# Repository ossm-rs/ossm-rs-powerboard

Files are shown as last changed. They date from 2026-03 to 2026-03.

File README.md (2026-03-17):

# OSSM-RS Powerboard

Power management PCB for AIM family motors, designed to pair with the Industrial ESP32-S3-RS485-CAN control board by Waveshare and run with OSSM-RS software.

This board is inspired by and builds on the OSSM hardware concept from KinkyMakers:
- OSSM-RS software: https://github.com/ossm-rs/ossm
- Original OSSM hardware/research: https://github.com/KinkyMakers/OSSM-hardware/tree/main

## What This Board Does

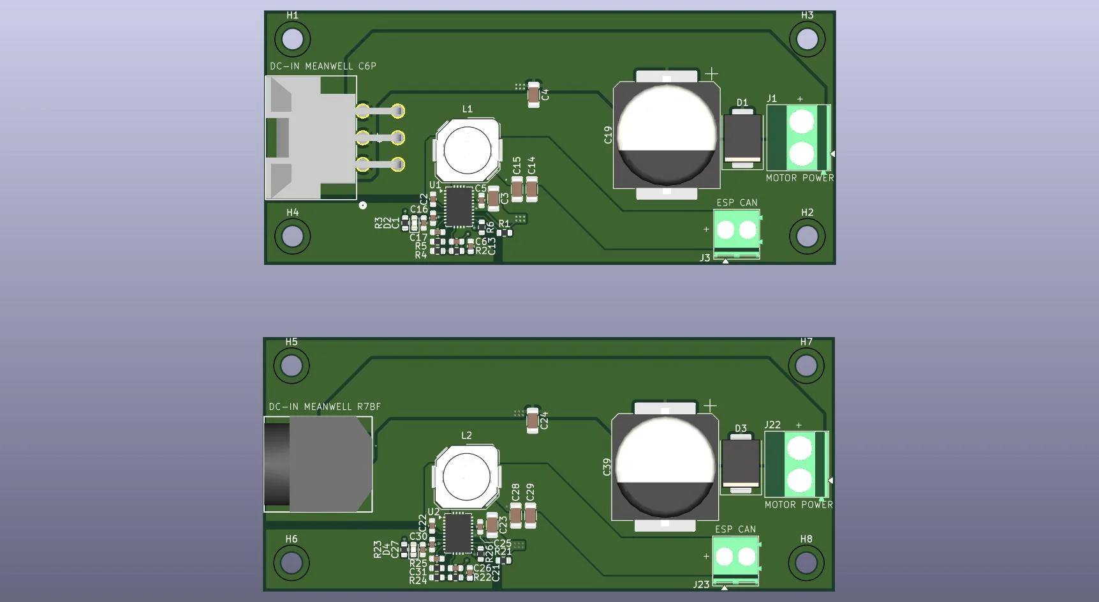
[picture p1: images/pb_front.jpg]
Powerboard diagram


- Accepts DC input from an external power supply.
- Provides 24-36v output for the servo motor.
- Protects from back EMF.
- Provides regulated 12V output for the controller board.
- Supports two input connector variants in this repository:
	- C6P input variant (Molex-style connector).
	- R7BF input variant (barrel jack style, Kycon KPJX-4S).

## System

- Motor family:
	- 60aim40F
	- 57aim30
- Controller:
	- Waveshare Industrial ESP32-S3-RS485-CAN
- PSU
    - Meanwell GST220A36-R7BF
    - Meanwell GST360A36-C6P

Other motor configurations that use 24-36V may also work, but they have not been validated on this board yet.

## Board Variants

- C6P variant:
	- Input connector: C6P 6 Pin Molex footprint
	- Fabrication files prefix: `C6P_*`
	- STEP model: `STEP/powerboard-C6P.step`
- R7BF variant:
	- Input connector: R7BF KPJX-4S footprint
	- Fabrication files prefix: `R7BF_*`
	- STEP model: `STEP/powerboard-R7BF.step`

Do not populate both input connector styles on the same board.

## Usage

- External PSU (C6P or R7BF style) feeds the selected DC-IN connector on this board.
- Motor power is provided at the Motor Power output terminal.
- 12V and GND for the Waveshare board are provided at the ESP/CAN power terminal.
- Motor control and comms (CAN/RS485) are handled by the Waveshare board and motor harness.
- Configure and run OSSM-RS from https://github.com/ossm-rs/ossm.

Use the wiring diagram image below and verify polarity before first power-up.

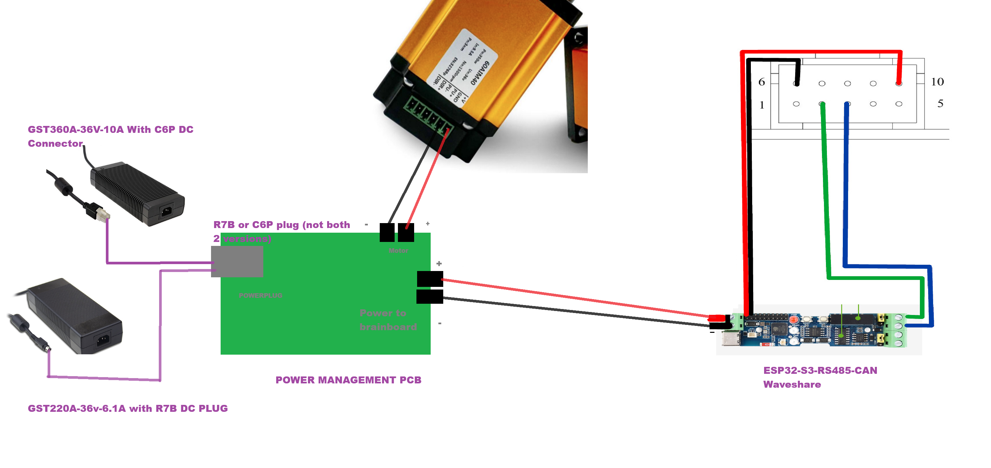
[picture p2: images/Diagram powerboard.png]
Powerboard wiring diagram


## Manufacturing

For assembly orders, use files in `jlcpcb-fabrication-files/`:
- `*_bom.csv` for component list
- `*_positions.csv` for pick-and-place positions

This project is intended for small community group buys through JLCPCB (or another PCB manufacturer). As of 2026-03-17, a typical minimum order on JLCPCB is 5 boards and costs about EUR 100 total.

Estimated cost per board:
- PCB-only share: about EUR 20 per board (EUR 100 / 5)
- With shipping split across 5 boards: about (EUR 100 + shipping) / 5 per board

## Safety Notes

- This is a high-current motor power board; incorrect wiring can damage electronics.
- Always verify connector pinout/polarity against schematic and wiring diagrams.
- Keep wiring secure and strain-relieved.

## Credits

- OSSM-RS maintainers and contributors
- KinkyMakers OSSM hardware project and community research

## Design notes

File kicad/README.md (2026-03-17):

# KiCad Project

Primary design source for the OSSM-RS powerboard.

## Main Files

- `pb-v1.kicad_sch`: Schematic
- `pb-v1.kicad_pcb`: PCB layout
- `pb-v1.kicad_pro`: KiCad project file
- `pb-v1.csv`: Consolidated BOM/export snapshot

## Project Libraries

- `project_symbols/`: Custom symbol libraries
- `project_footprints/`: Custom footprints
- `project_3dshapes/`: 3D models used by footprints

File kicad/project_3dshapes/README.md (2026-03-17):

# project_3dshapes

3D CAD models referenced by custom footprints in this project.

## Contents

This folder includes STEP/IGS/WRL models for:
- Input connectors
- Inductor package
- Regulator or other mechanical-critical parts

## Notes

- Keep model filenames stable once footprints reference them.
- If replacing a model, verify orientation and origin in PCB 3D viewer.
- Prefer STEP for mechanical exchange and keep WRL only when needed by KiCad view pipeline.

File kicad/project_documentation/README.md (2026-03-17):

# project_documentation

Project-local documentation files related to the KiCad design.

## Typical Content

- Design decision notes
- Constraint summaries
- Revision/change logs for PCB updates
- Internal assembly notes for the board

This folder is currently a placeholder and can be expanded as project notes are formalized.

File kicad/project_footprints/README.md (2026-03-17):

# project_footprints

Custom KiCad footprints used by this powerboard project.

## Current Footprints

- `CONN_SDA-42404_06_MOL.kicad_mod`
- `KPJX4S.kicad_mod`
- `KPJX4SS.kicad_mod`
- `L_Wurth_WE-PD-1050P.kicad_mod`

## Maintenance Notes

- Keep courtyard, fab, and 3D model alignment consistent.
- Validate pad numbering against datasheets before release.
- Re-run DRC after footprint updates.

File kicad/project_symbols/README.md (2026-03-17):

# project_symbols

Custom KiCad symbols used in the OSSM-RS powerboard schematic.

## Current Files

- `2026-01-18_19-45-22.kicad_sym`
- `Inductor_Wurth_WE-PD.kicad_sym`
- `KPJX-4S-S.kicad_sym`
- `KPJX-4S.kicad_sym`

## Maintenance Notes

- Keep symbol pin names/numbers synchronized with corresponding footprints.
- Add datasheet links and key fields (MPN, voltage/current where relevant).
- Run ERC after symbol changes.

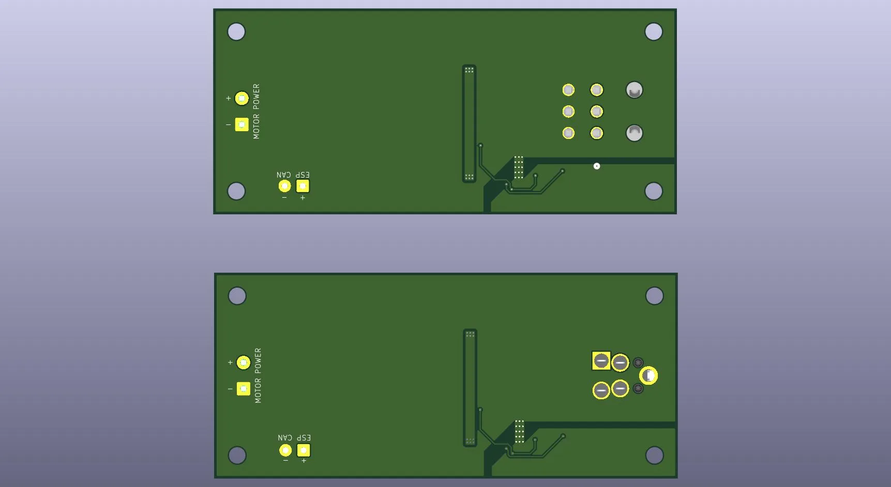
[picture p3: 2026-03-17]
images/pb_back.jpg

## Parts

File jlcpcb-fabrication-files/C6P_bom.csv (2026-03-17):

Designator | Footprint | Quantity | Value | LCSC Part #
C1 | 0603 | 1 | 1uF | C15849
C13, C5 | 0603 | 2 | 100nF | C14663
C14, C15, C3, C4 | 1206 | 4 | 10uF | C89632
C16 | 0603 | 1 | 2.2uF | C23630
C19 | CP_Elec_16x17.5 | 1 | 1mF | C2164559
C2 | 0603 | 1 | 470nF | C1623
C6 | 0603 | 1 | 5.1pF | C61816
D1 | D_SMC | 1 | SMCJ40CA | C80273
D2 | 0603 | 1 | GREEN | C12065
J1 | TerminalBlock_Phoenix_MKDS-1,5-2-5.08_1x02_P5.08mm_Horizontal | 1 | Motor Power | C8465
J3 | TerminalBlock_Phoenix_PT-1,5-2-3.5-H_1x02_P3.50mm_Horizontal | 1 | 12V ESP CAN | C466970
J4 | CONN_SDA-42404_06_MOL | 1 | Molex 15246060 | C563687
L1 | L_Wurth_WE-PD-1050P | 1 | 22uH | C2651173
R1, R2 | 0603 | 2 | 100k | C25803
R3 | 0603 | 1 | 10k | C25804
R4 | 0603 | 1 | 9.1k | C23260
R6 | 0603 | 1 | 100 | C22775
U1 | Texas_RNP0030B_WQFN-30-1EP_4x6mm_P0.5mm_EP1.8x4.5mm_ThermalVias | 1 | LM76003 | C470958

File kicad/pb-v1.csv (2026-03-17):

Reference | Qty | Value | DNP | Exclude from BOM | Exclude from Board | Footprint | Datasheet | MPN | Voltage
C1,C21 | 2 | 1uF |  |  |  | Capacitor_SMD:C_0603_1608Metric | ~ | C15849 | 50V
C2,C22 | 2 | 470nF |  |  |  | Capacitor_SMD:C_0603_1608Metric | ~ | C1623 | 25V
C3,C4,C14,C15,C23,C24,C28,C29 | 8 | 10uF |  |  |  | Capacitor_SMD:C_1206_3216Metric | ~ | C89632 | 25V,50V
C5,C13,C25,C27 | 4 | 100nF |  |  |  | Capacitor_SMD:C_0603_1608Metric | ~ | C14663 | 25V,50V
C6,C26 | 2 | 5.1pF |  |  |  | Capacitor_SMD:C_0603_1608Metric | ~ | C61816
C16,C30 | 2 | 2.2uF |  |  |  | Capacitor_SMD:C_0603_1608Metric | ~C100082 | C23630 | 16V
C17,C31 | 2 | 10nF | DNP |  |  | Capacitor_SMD:C_0603_1608Metric | ~ | C57112 | 50V
C19,C39 | 2 | 1mF |  |  |  | Capacitor_SMD:CP_Elec_16x17.5 | ~865060663015 | C2164559 | 50V
D1,D3 | 2 | D_TVS |  |  |  | Diode_SMD:D_SMC | ~ | C80273
D2,D4 | 2 | GREEN |  |  |  | LED_SMD:LED_0603_1608Metric | ~ | C12065
H1,H2,H3,H4,H5,H6,H7,H8 | 8 | MountingHole |  | Excluded from BOM |  | MountingHole:MountingHole_3.2mm_M3_DIN965 | ~ | -
J1,J22 | 2 | Motor Power |  |  |  | TerminalBlock_Phoenix:TerminalBlock_Phoenix_MKDS-1,5-2-5.08_1x02_P5.08mm_Horizontal | ~ | C8465
J3,J23 | 2 | 12V ESP CAN |  |  |  | TerminalBlock_Phoenix:TerminalBlock_Phoenix_PT-1,5-2-3.5-H_1x02_P3.50mm_Horizontal | ~ | C466970
J4 | 1 | Conn_01x06 |  |  |  | project_footprints:CONN_SDA-42404_06_MOL | ~ | C563687
J21 | 1 | KPJX-4S |  |  |  | project_footprints:KPJX4S | https://www.kycon.com/Pub_Eng_Draw/KPJX-4S.pdf | C7212564
L1,L2 | 2 | 22uH |  |  |  | project_footprints:L_Wurth_WE-PD-1050P | ~7447714220 | C2651173
R1,R2,R21,R22 | 4 | 100k |  |  |  | Resistor_SMD:R_0603_1608Metric | ~ | C25803
R3,R23 | 2 | 10k |  |  |  | Resistor_SMD:R_0603_1608Metric | ~ | C25804
R4,R24 | 2 | 9.1k |  |  |  | Resistor_SMD:R_0603_1608Metric | ~ | C23260
R5,R25 | 2 | 82k | DNP |  |  | Resistor_SMD:R_0603_1608Metric | ~ | C23254
R6,R26 | 2 | 100 |  |  |  | Resistor_SMD:R_0603_1608Metric | ~ | C22775
U1,U2 | 2 | LM76003 |  |  |  | Package_DFN_QFN:Texas_RNP0030B_WQFN-30-1EP_4x6mm_P0.5mm_EP1.8x4.5mm_ThermalVias | https://www.ti.com/lit/ds/symlink/lm76003.pdf | C470958

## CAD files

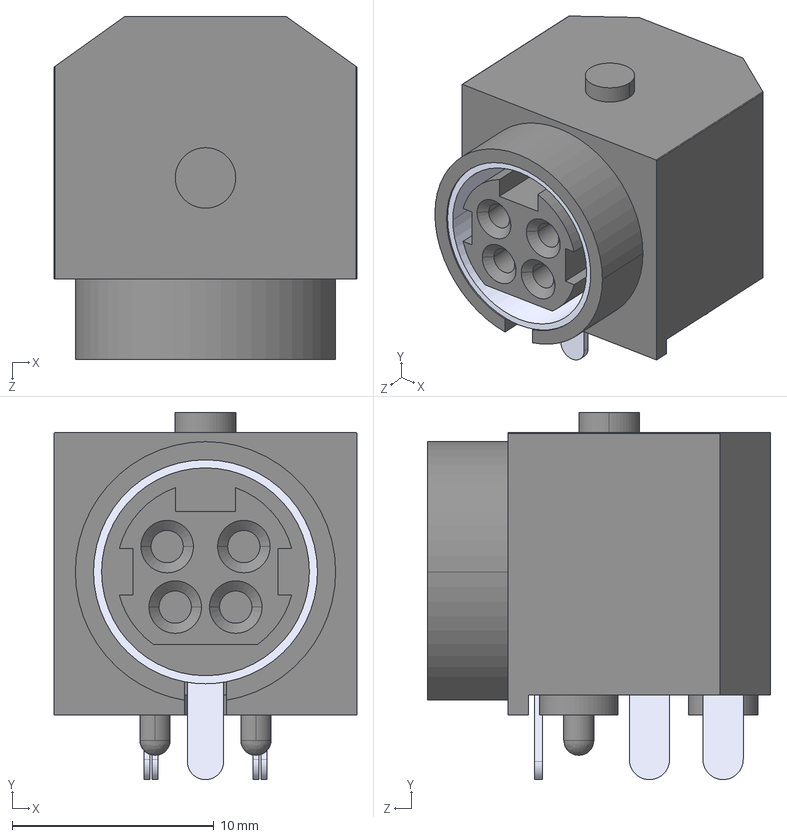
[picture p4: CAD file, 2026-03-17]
kicad/project_3dshapes/KPJX-4S.stp
15.0 x 18.2 x 17.0 mm

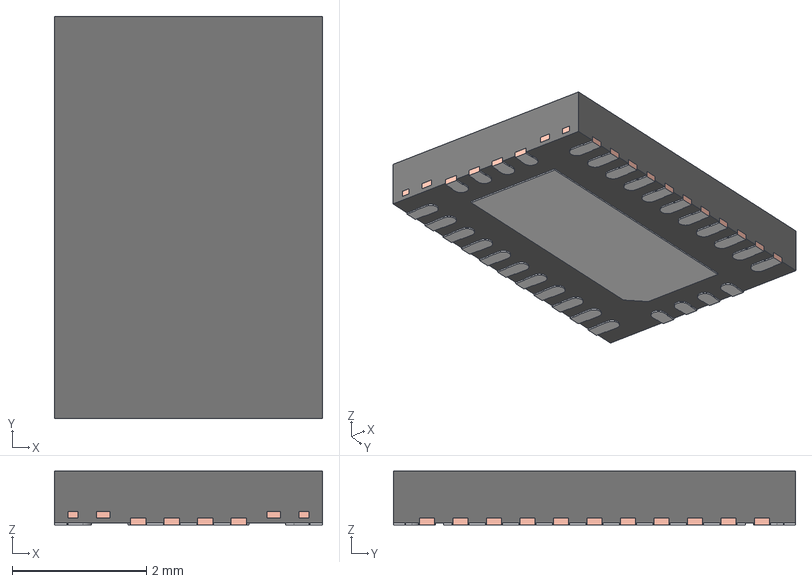
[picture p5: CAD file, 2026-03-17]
kicad/project_3dshapes/RNP0030G.stp
4.00 x 6.00 x 0.8 mm
BODY-QFN
FRAME
PIN1-ID

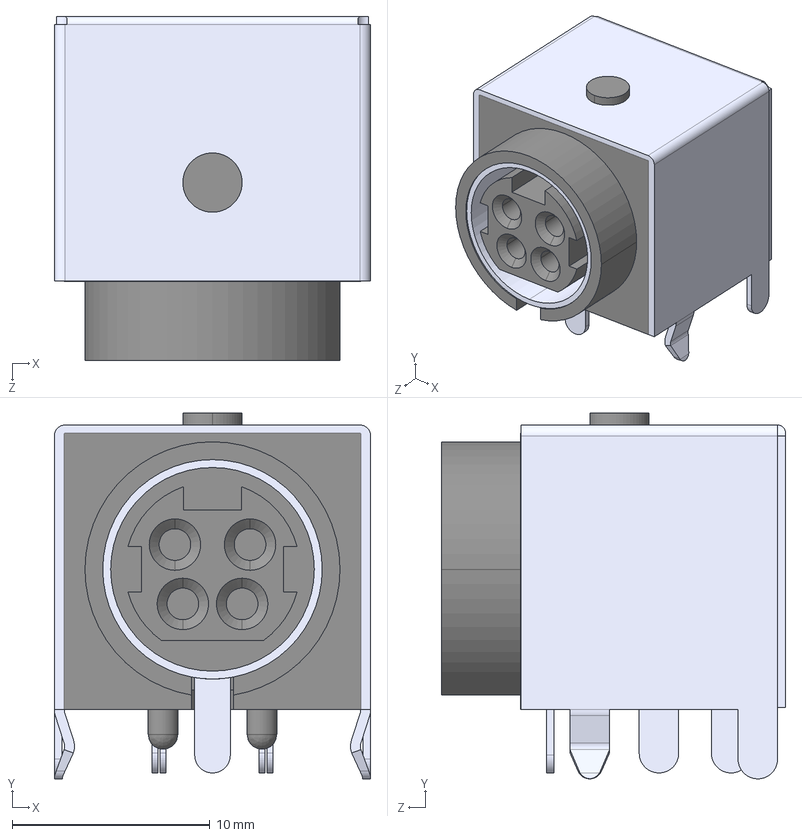
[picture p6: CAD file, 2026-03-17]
kicad/project_3dshapes/KPJX-4S-S.stp
16.0 x 18.5 x 17.4 mm

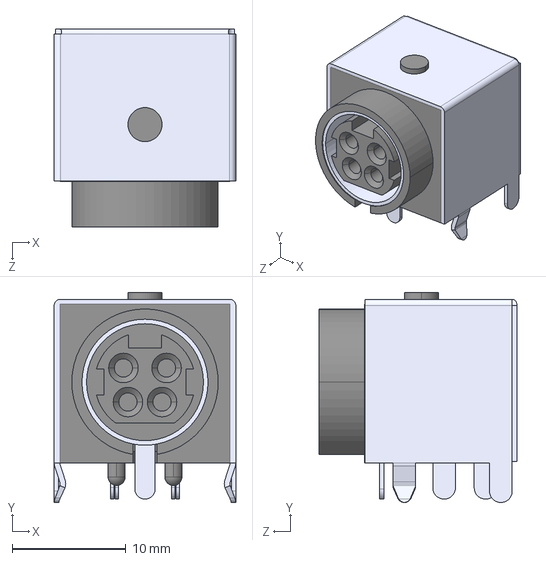
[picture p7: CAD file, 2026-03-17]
kicad/project_3dshapes/KPJX-4S-S_A.STEP
16.0 x 18.5 x 17.4 mm

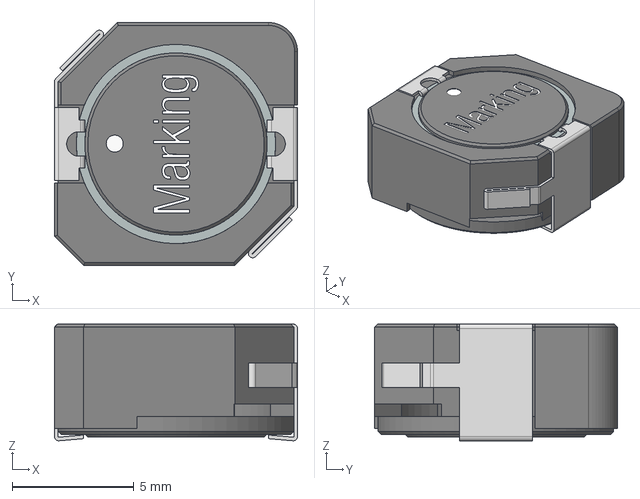
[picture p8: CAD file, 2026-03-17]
kicad/project_3dshapes/L_Wurth_WE-PD-1050P.step
10.0 x 10.0 x 4.80 mm

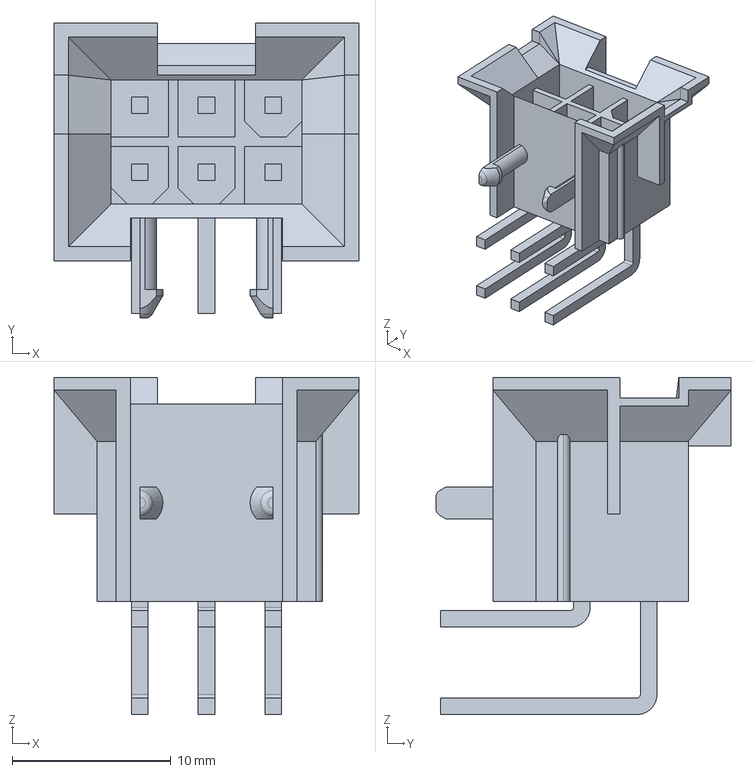
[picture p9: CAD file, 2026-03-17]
kicad/project_3dshapes/0015246060.stp
19.2 x 18.6 x 21.2 mm

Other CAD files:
kicad/project_3dshapes/KPJX-4S_A.STEP
kicad/project_3dshapes/0015246060.igs

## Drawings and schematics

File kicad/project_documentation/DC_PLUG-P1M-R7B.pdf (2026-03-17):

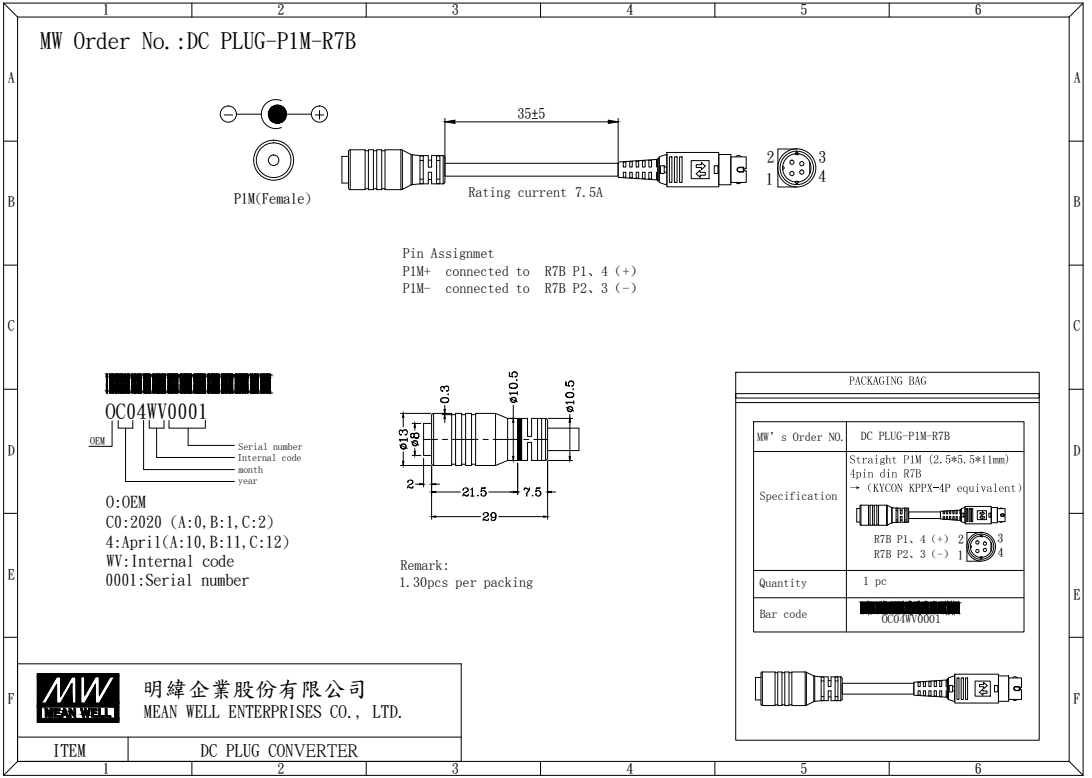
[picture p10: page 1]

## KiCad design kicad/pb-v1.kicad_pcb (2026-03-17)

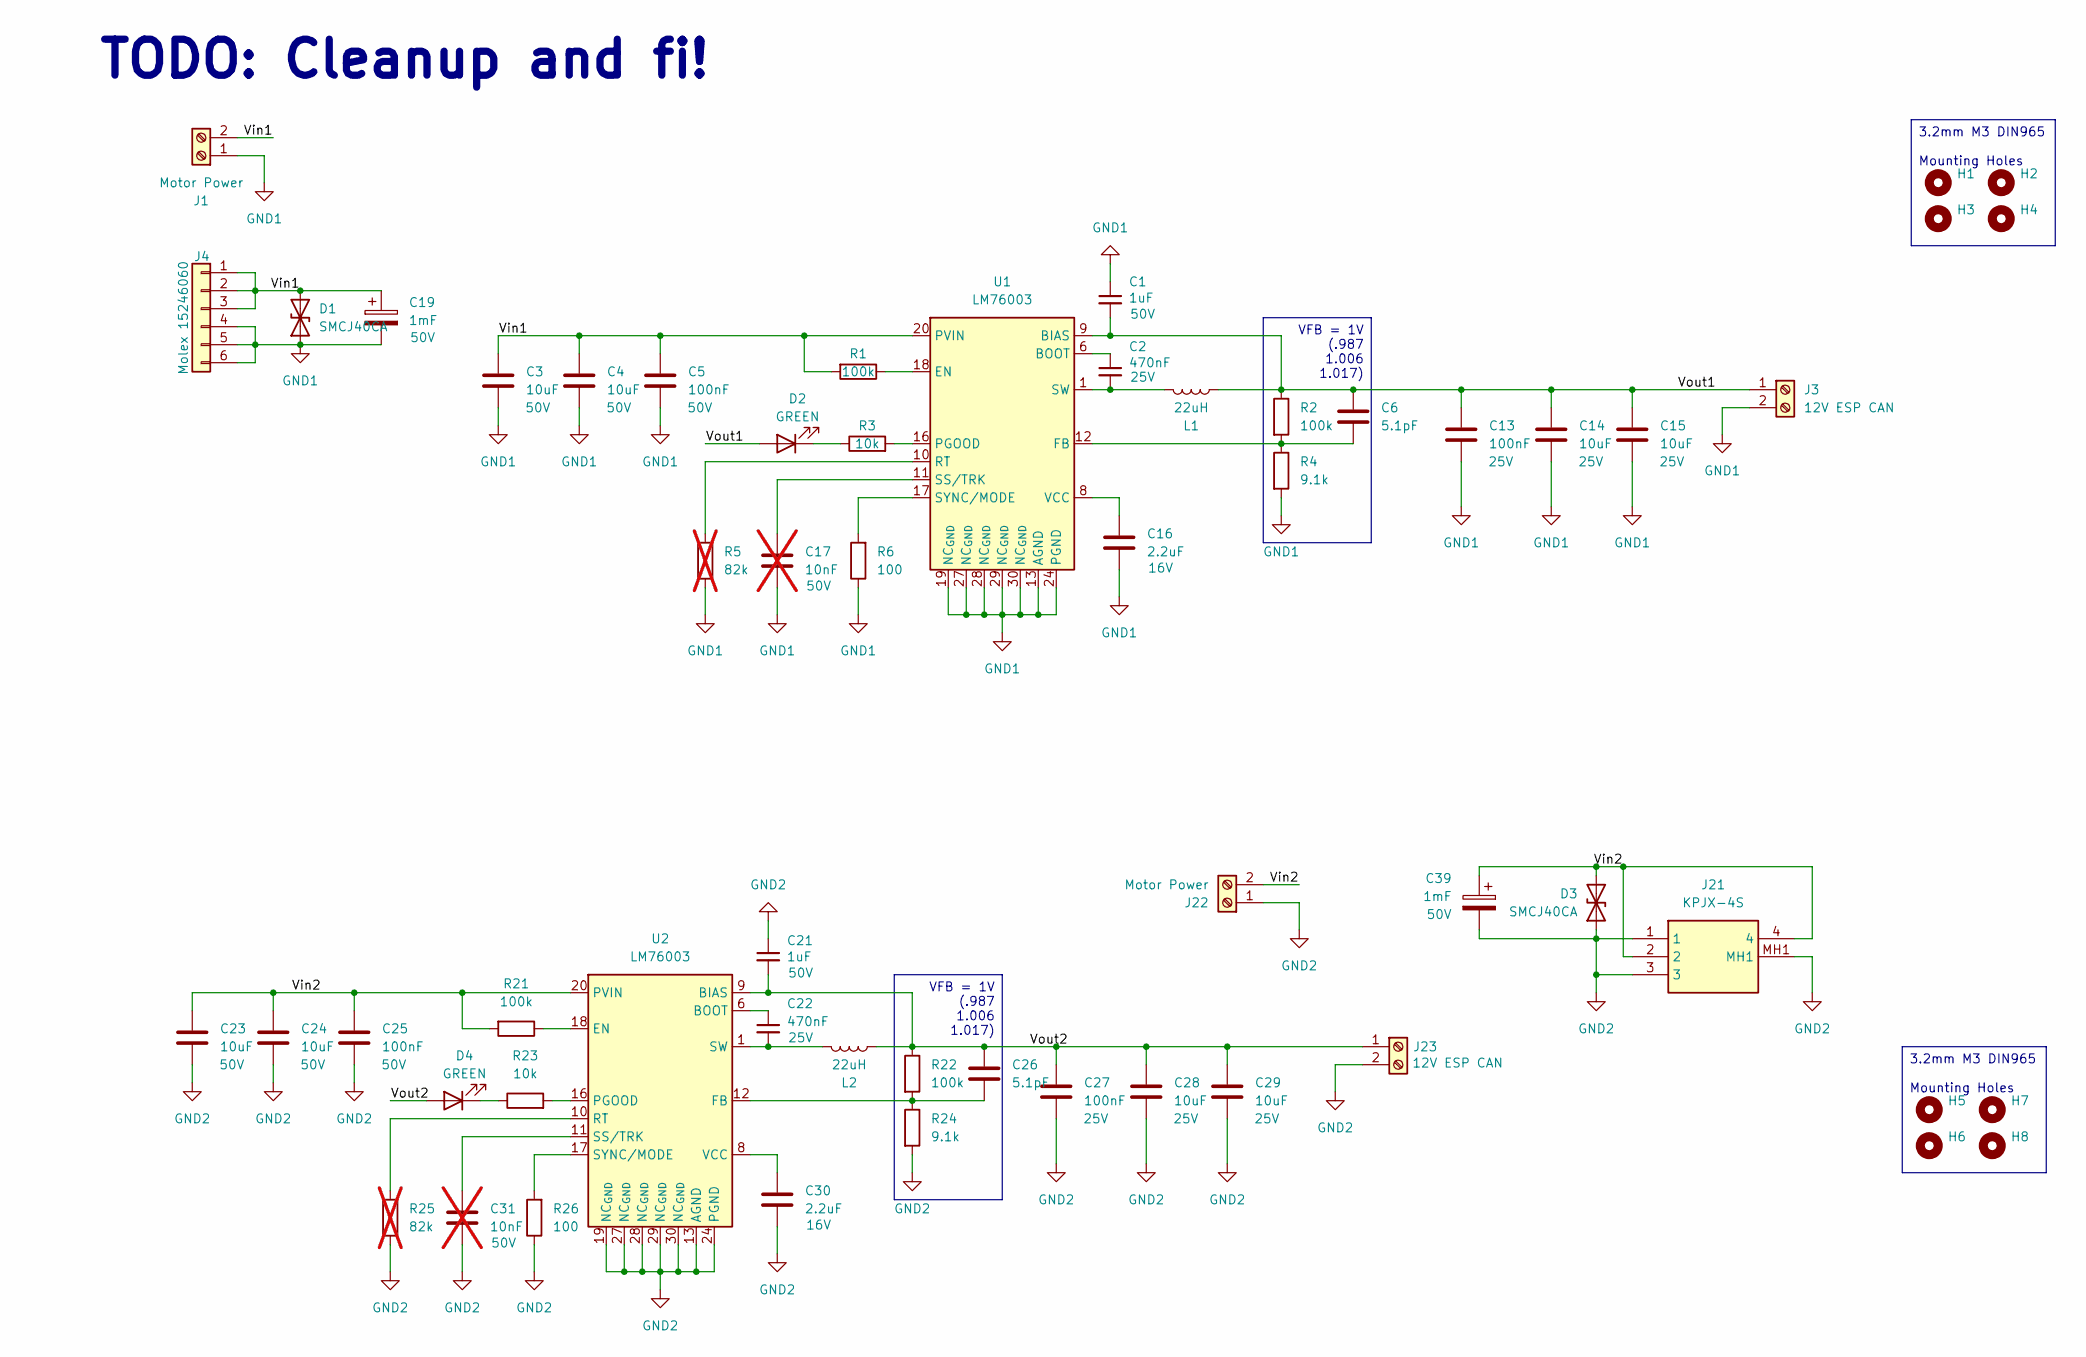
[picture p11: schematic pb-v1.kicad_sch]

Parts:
C1, C21: 1uF; C_0603_1608Metric; Voltage 50V; MPN C15849
C2, C22: 470nF; C_0603_1608Metric; Voltage 25V; MPN C1623
C3, C4, C23, C24: 10uF; C_1206_3216Metric; Voltage 50V; MPN C89632
C5, C25: 100nF; C_0603_1608Metric; Voltage 50V; MPN C14663
C6, C26: 5.1pF; C_0603_1608Metric; MPN C61816
C13, C27: 100nF; C_0603_1608Metric; Voltage 25V; MPN C14663
C14, C15, C28, C29: 10uF; C_1206_3216Metric; Voltage 25V; MPN C89632
C16, C30: 2.2uF; C_0603_1608Metric; Voltage 16V; MPN C23630
C17, C31: 10nF; C_0603_1608Metric; Voltage 50V; MPN C57112; not fitted
C19, C39: 1mF; CP_Elec_16x17.5; Voltage 50V; MPN C2164559
D1, D3: SMCJ40CA; D_SMC; MPN C80273
D2, D4: GREEN; LED_0603_1608Metric; MPN C12065
H1, H2, H3, H4, H5, H6, H7, H8: MountingHole; MountingHole_3.2mm_M3_DIN965
J1, J22: Motor Power; TerminalBlock_Phoenix_MKDS-1,5-2-5.08_1x02_P5.08mm_Horizont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; MPN C8465
J3, J23: 12V ESP CAN; TerminalBlock_Phoenix_PT-1,5-2-3.5-H_1x02_P3.50mm_Horizontal; MPN C466970
J4: Molex 15246060; CONN_SDA-42404_06_MOL; MPN C563687
J21: KPJX-4S; KPJX4S; Manufacturer_Part_Number KPJX-4S; Mouser Part Number 806-KPJX-4S
L1, L2: 22uH; L_Wurth_WE-PD-1050P; MPN C2651173
R1, R2, R21, R22: 100k; R_0603_1608Metric; MPN C25803
R3, R23: 10k; R_0603_1608Metric; MPN C25804
R4, R24: 9.1k; R_0603_1608Metric; MPN C23260
R5, R25: 82k; R_0603_1608Metric; MPN C23254; not fitted
R6, R26: 100; R_0603_1608Metric; MPN C22775
U1, U2: LM76003; Texas_RNP0030B_WQFN-30-1EP_4x6mm_P0.5mm_EP1.8x4.5mm_Thermal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; MPN C470958

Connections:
/Vin1: C3.1, C4.1, C5.1, C19.1, D1.2 (A2), J1.2, J4.1, J4.2, J4.3, R1.2, U1.20 (PVIN), U1.21 (PVIN), U1.22 (PVIN)
/Vin2: C23.1, C24.1, C25.1, C39.1, D3.2 (A2), J21.2, J21.4, J22.2, R21.2, U2.20 (PVIN), U2.21 (PVIN), U2.22 (PVIN)
/Vout1: C1.2, C6.1, C13.1, C14.1, C15.1, D2.2 (A), J3.1, L1.2, R2.1, U1.9 (BIAS)
/Vout2: C21.2, C26.1, C27.1, C28.1, C29.1, D4.2 (A), J23.1, L2.2, R22.1, U2.9 (BIAS)
GND1: C1.1, C3.2, C4.2, C5.2, C13.2, C14.2, C15.2, C16.2, C17.2, C19.2, D1.1 (A1), J1.1, J3.2, J4.4, J4.5, J4.6, R4.2, R5.1, R6.1, U1.13 (AGND), U1.14 (AGND), U1.15 (AGND), U1.19 (NC_{GND}), U1.24 (PGND), U1.25 (PGND), U1.26 (PGND), U1.27 (NC_{GND}), U1.28 (NC_{GND}), U1.29 (NC_{GND}), U1.30 (NC_{GND}), U1.31 (AGND)
GND2: C21.1, C23.2, C24.2, C25.2, C27.2, C28.2, C29.2, C30.2, C31.2, C39.2, D3.1 (A1), J21.1, J21.3, J21.MH1, J22.1, J23.2, R24.2, R25.1, R26.1, U2.13 (AGND), U2.14 (AGND), U2.15 (AGND), U2.19 (NC_{GND}), U2.24 (PGND), U2.25 (PGND), U2.26 (PGND), U2.27 (NC_{GND}), U2.28 (NC_{GND}), U2.29 (NC_{GND}), U2.30 (NC_{GND}), U2.31 (AGND)
unnamed: C2.2, L1.1, U1.1 (SW), U1.2 (SW), U1.3 (SW), U1.4 (SW), U1.5 (SW)
unnamed: C22.2, L2.1, U2.1 (SW), U2.2 (SW), U2.3 (SW), U2.4 (SW), U2.5 (SW)
unnamed: D2.1 (K), R3.1
unnamed: D4.1 (K), R23.1
unnamed: C2.1, U1.6 (BOOT)
unnamed: R1.1, U1.18 (EN)
unnamed: C6.2, R2.2, R4.1, U1.12 (FB)
unnamed: R3.2, U1.16 (PGOOD)
unnamed: R5.2, U1.10 (RT)
unnamed: C17.1, U1.11 (SS/TRK)
unnamed: R6.2, U1.17 (SYNC/MODE)
unnamed: C16.1, U1.8 (VCC)
unnamed: C22.1, U2.6 (BOOT)
unnamed: R21.1, U2.18 (EN)
unnamed: C26.2, R22.2, R24.1, U2.12 (FB)
unnamed: R23.2, U2.16 (PGOOD)
unnamed: R25.2, U2.10 (RT)
unnamed: C31.1, U2.11 (SS/TRK)
unnamed: R26.2, U2.17 (SYNC/MODE)
unnamed: C30.1, U2.8 (VCC)

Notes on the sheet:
TODO: Cleanup and fi!
VFB = 1V (.987 1.006 1.017)
3.2mm M3 DIN965 Mounting Holes

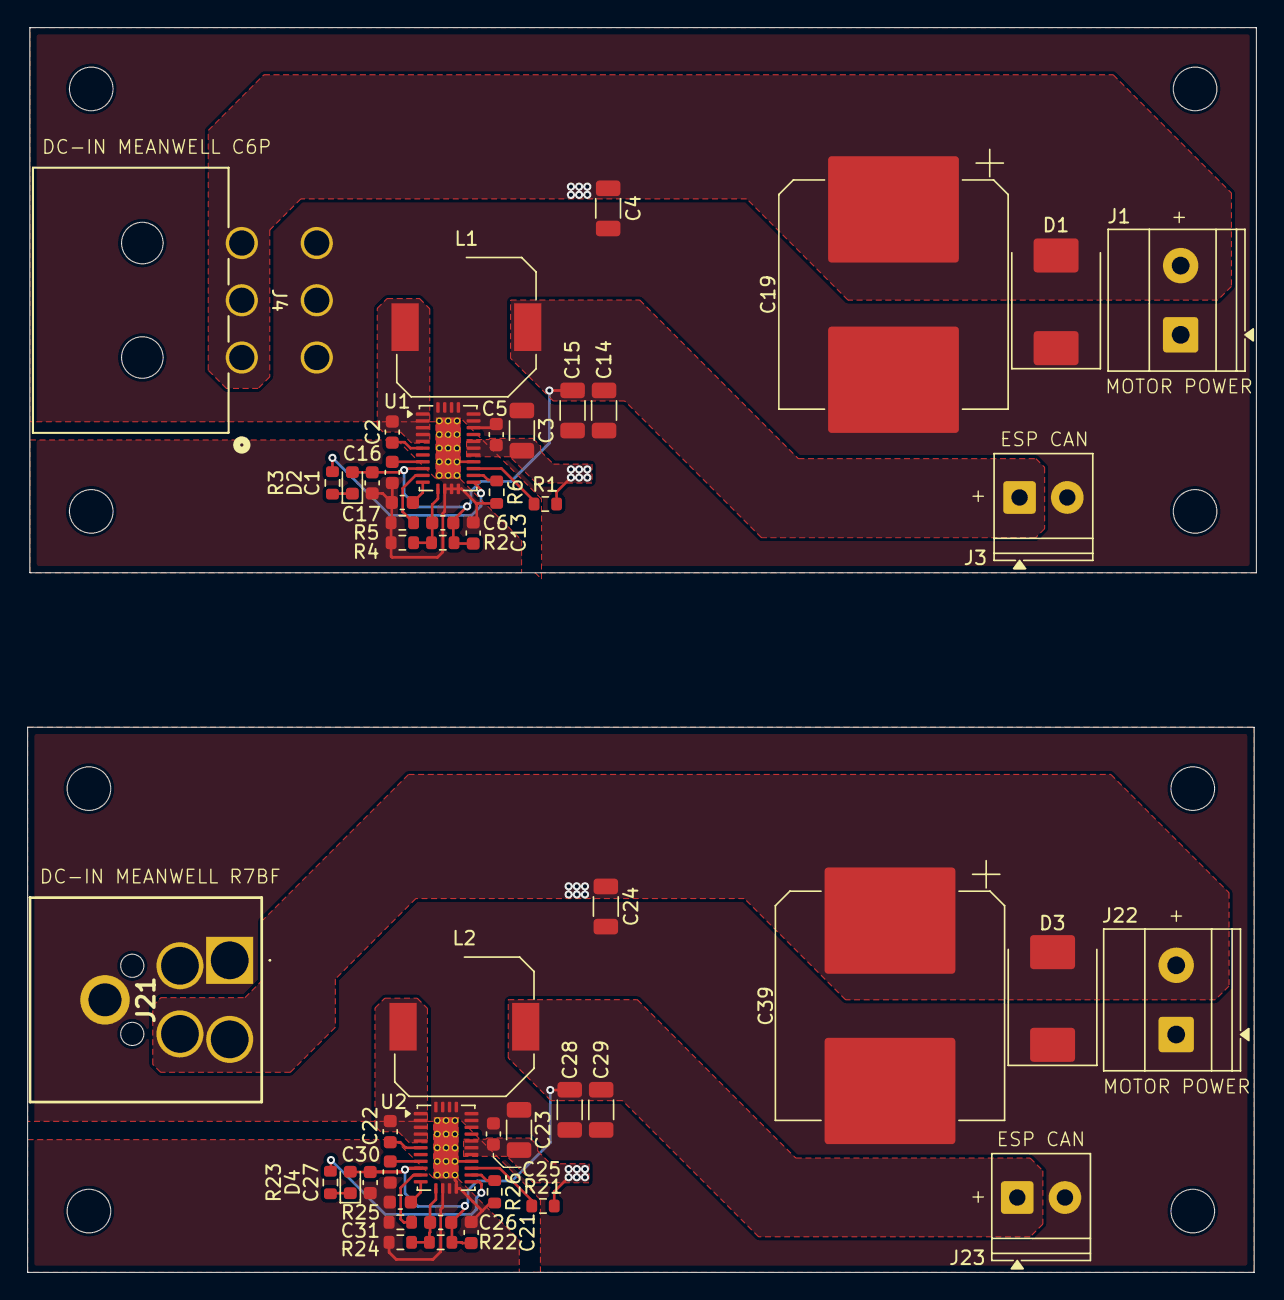
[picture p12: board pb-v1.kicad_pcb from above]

Board: 2 copper layers, 90.2 x 91.3 mm, 58 parts (0 on the bottom side), 26 nets.

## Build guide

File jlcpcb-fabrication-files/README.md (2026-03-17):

# JLCPCB Fabrication Files

Manufacturing and assembly inputs for the two powerboard connector variants.

## Files

- `C6P_bom.csv`: BOM for the C6P input connector variant
- `C6P_positions.csv`: Pick-and-place for C6P variant
- `R7BF_bom.csv`: BOM for the R7BF input connector variant
- `R7BF_positions.csv`: Pick-and-place for R7BF variant

## How To Use

1. Choose one variant only (`C6P` or `R7BF`).
2. Go to: https://cart.jlcpcb.com 
3. Upload the matching Gerbers.
4. Upload the matching BOM and positions CSV from this folder.
5. Verify connector footprints and rotations before confirming assembly.

## Important

- Do not mix BOM and positions across variants.
- The input connector differs between variants; rest of the design is largely shared.

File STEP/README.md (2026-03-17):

# STEP Models

Mechanical exports of the assembled powerboard variants.

## Files

- `powerboard-C6P.step`: C6P connector variant
- `powerboard-R7BF.step`: R7BF connector variant

## Usage

Use these files for enclosure design, collision checks, and system-level CAD integration with motor/controller hardware.

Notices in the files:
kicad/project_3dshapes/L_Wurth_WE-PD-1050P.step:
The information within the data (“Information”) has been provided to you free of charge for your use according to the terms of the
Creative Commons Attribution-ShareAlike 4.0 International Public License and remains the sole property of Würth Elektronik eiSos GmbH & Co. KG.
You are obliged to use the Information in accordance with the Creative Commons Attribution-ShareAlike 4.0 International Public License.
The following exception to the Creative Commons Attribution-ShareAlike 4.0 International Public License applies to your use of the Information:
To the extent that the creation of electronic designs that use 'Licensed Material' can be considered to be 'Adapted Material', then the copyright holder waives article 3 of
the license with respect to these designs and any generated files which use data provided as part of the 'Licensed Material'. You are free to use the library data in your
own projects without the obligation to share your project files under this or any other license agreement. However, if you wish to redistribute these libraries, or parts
